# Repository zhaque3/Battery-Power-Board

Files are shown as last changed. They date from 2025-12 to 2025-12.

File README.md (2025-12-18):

# Battery Power Board

**Project:** Battery Power Board — power distribution, monitoring, and telemetry board for the University of Alberta EcoCar Prototype Vehicle.

**Vehicle:** 2025 Hydrogen Prototype (Sally). 1st Place, Shell Eco Marathon Hydrogen Prototype Category  
**Competition Year:** 2025

<p align="center">
  
</p>

---

## Overview

The Battery Power Board serves as the central power monitoring and distribution interface between the vehicle’s energy sources and downstream subsystems.  

It measures battery and regulated rail voltages and currents, monitors thermal conditions, computes energy usage, and communicates system status over the vehicle CAN bus.

---

## Key Functions

- Monitor battery input voltage and current
- Measure regulated output rails (12 V and 7 V)
- Monitor thermal conditions of critical power components
- Track energy consumption over time
- Display live system data on a local OLED
- Communicate telemetry and fault states over CAN bus
- Respond to vehicle safety events (e.g. hydrogen alarm)

---

## Power Architecture

### Input

- Battery input monitored via voltage divider
- Hall effect current sensing
- Designed for continuous monitoring under dynamic load conditions

### Output Rails

- **12 V Rail**
  - Voltage and current monitored
  - Supplies downstream electronics and subsystems
- **7 V Rail**
  - Voltage and current monitored
  - Intended for low power or auxiliary loads

---

## Sensing & Measurement

### Electrical Measurements

The board continuously measures:

- Battery input voltage
- Battery input current
- 12 V output voltage
- 12 V output current
- 7 V output voltage
- 7 V output current

These measurements allow real time estimation of power flow and system loading.

### Thermal Monitoring

- Multiple analog temperature sensors placed near:
  - Buck regulator
  - Output power stage
  - Control electronics
- Enables detection of abnormal thermal conditions during operation

---

## Energy Tracking

The board integrates measured voltage and current over time to estimate energy usage (joules).  
This data is used for:

- Efficiency analysis
- Post run performance evaluation
- Competition strategy optimization

---

## Local User Interface

- **SSD1306 OLED display**
- Displays:
  - Battery voltage and current
  - Output rail voltages and currents
  - Temperatures of key components
- Automatically switches to an alarm display when a fault condition is received

This allows quick diagnostics during testing without external tools.

---

## CAN Bus Integration

- Fully integrated into the vehicle CAN network
- Transmits:
  - Electrical measurements
  - Thermal data
  - System status flags
- Receives:
  - Safety and fault signals (e.g., hydrogen alarm)
  - Synchronization or status commands from other vehicle modules

The board reacts immediately to safety critical CAN messages by updating system state and user display.

---

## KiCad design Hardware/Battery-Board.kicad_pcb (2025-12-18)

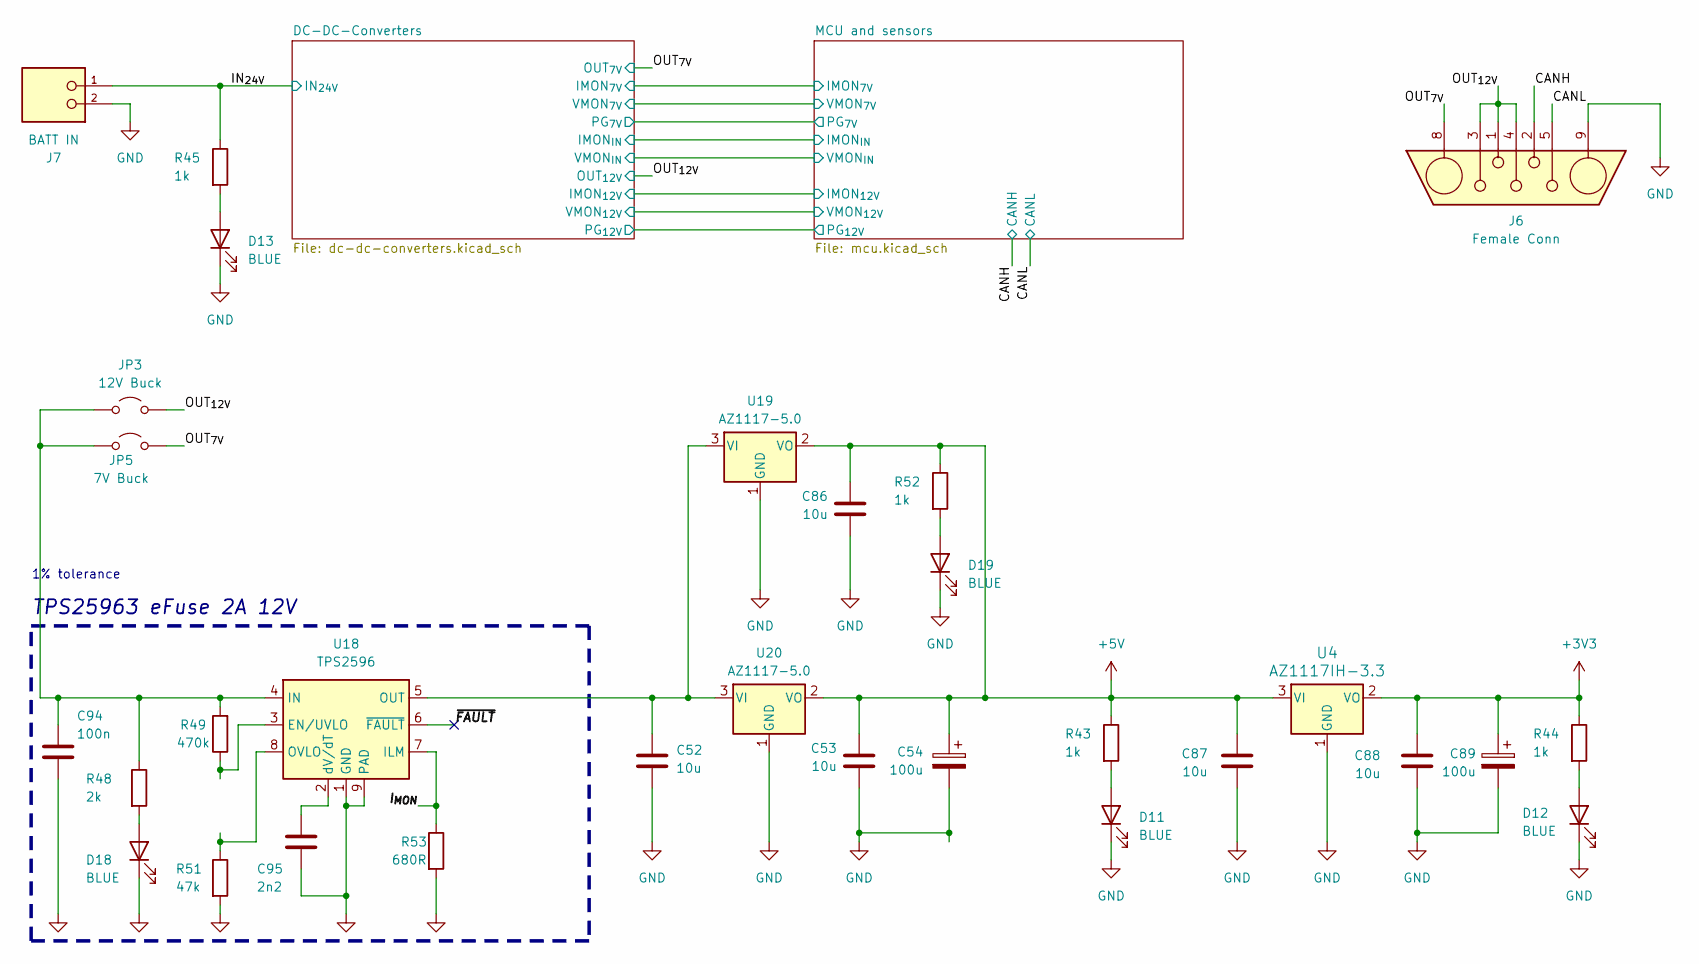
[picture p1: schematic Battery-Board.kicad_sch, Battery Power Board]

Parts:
C52, C53, C86, C87, C88: 10u; C_0805_2012Metric; LCSC# C15850
C54, C89: 100u; CP_Elec_6.3x9.9; LCSC# C72478
C94: 100n; C_0603_1608Metric; JLCPCB Part#(Optional) C28233
C95: 2n2; C_0603_1608Metric; JLCPCB Part#(Optional) C1531
D11, D12, D13, D18, D19: BLUE; LED_0603_1608Metric
J6: Female Conn; DB7W2-Female
J7: BATT IN; PHOENIX_1017521; PARTREV 04.01.2018
JP3: 12V Buck; J_0603_Triangular
JP5: 7V Buck; J_0603_Triangular
R43, R44, R45, R52: 1k; R_0603_1608Metric
R48: 2k; R_0603_1608Metric; JLCPCB Part#(Optional) C17604
R49: 470k; R_0603_1608Metric; JLCPCB Part#(optional) C17709
R51: 47k; R_0603_1608Metric; JLCPCB Part#(optional) C17713
R53: 680R; R_0603_1608Metric; JLCPCB Part#(Optional) C23220
U4: AZ1117IH-3.3; SOT-223-3_TabPin2
U18: TPS2596; TI_SO-PowerPAD-8
U19, U20: AZ1117-5.0; SOT-223-3_TabPin2

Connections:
+3V3: C88.1, C89.1, R44.1, U4.2 (VO); also elsewhere on the board
+5V: C53.1, C54.1, C86.1, C87.1, R43.1, R52.1, U4.3 (VI), U19.2 (VO), U20.2 (VO); also elsewhere on the board
/CANH: J6.2; also elsewhere on the board
/CANL: J6.5; also elsewhere on the board
/IN_{24V}: J7.1, R45.1; also elsewhere on the board
/I_{MON}: R53.1, U18.7 (ILM)
/OUT_{7V}: J6.8, JP5.2 (B); also elsewhere on the board
/OUT_{12V}: J6.1, J6.3, J6.4, JP3.2 (B); also elsewhere on the board
/~FAULT: U18.6 (~FAULT)
GND: C52.2, C53.2, C54.2, C86.2, C87.2, C88.2, C89.2, C94.2, C95.2, D11.1 (K), D12.1 (K), D13.1 (K), D18.1 (K), D19.1 (K), J6.9, J7.2, R51.2, R53.2, U4.1 (GND), U18.1 (GND), U18.9 (PAD), U19.1 (GND), U20.1 (GND); also elsewhere on the board
unnamed: D11.2 (A), R43.2
unnamed: D12.2 (A), R44.2
unnamed: D13.2 (A), R45.2
unnamed: D18.2 (A), R48.2
unnamed: D19.2 (A), R52.2
unnamed: C94.1, JP3.1 (A), JP5.1 (A), R48.1, R49.2, U18.4 (IN)
unnamed 90: R49.1, U18.3 (EN/UVLO); also elsewhere on the board
unnamed: C52.1, U18.5 (OUT), U19.3 (VI), U20.3 (VI)
unnamed 92: R51.1, U18.8 (OVLO); also elsewhere on the board
unnamed: C95.1, U18.2 (dV/dT)

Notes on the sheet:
TPS25963 eFuse 2A 12V
1% tolerance

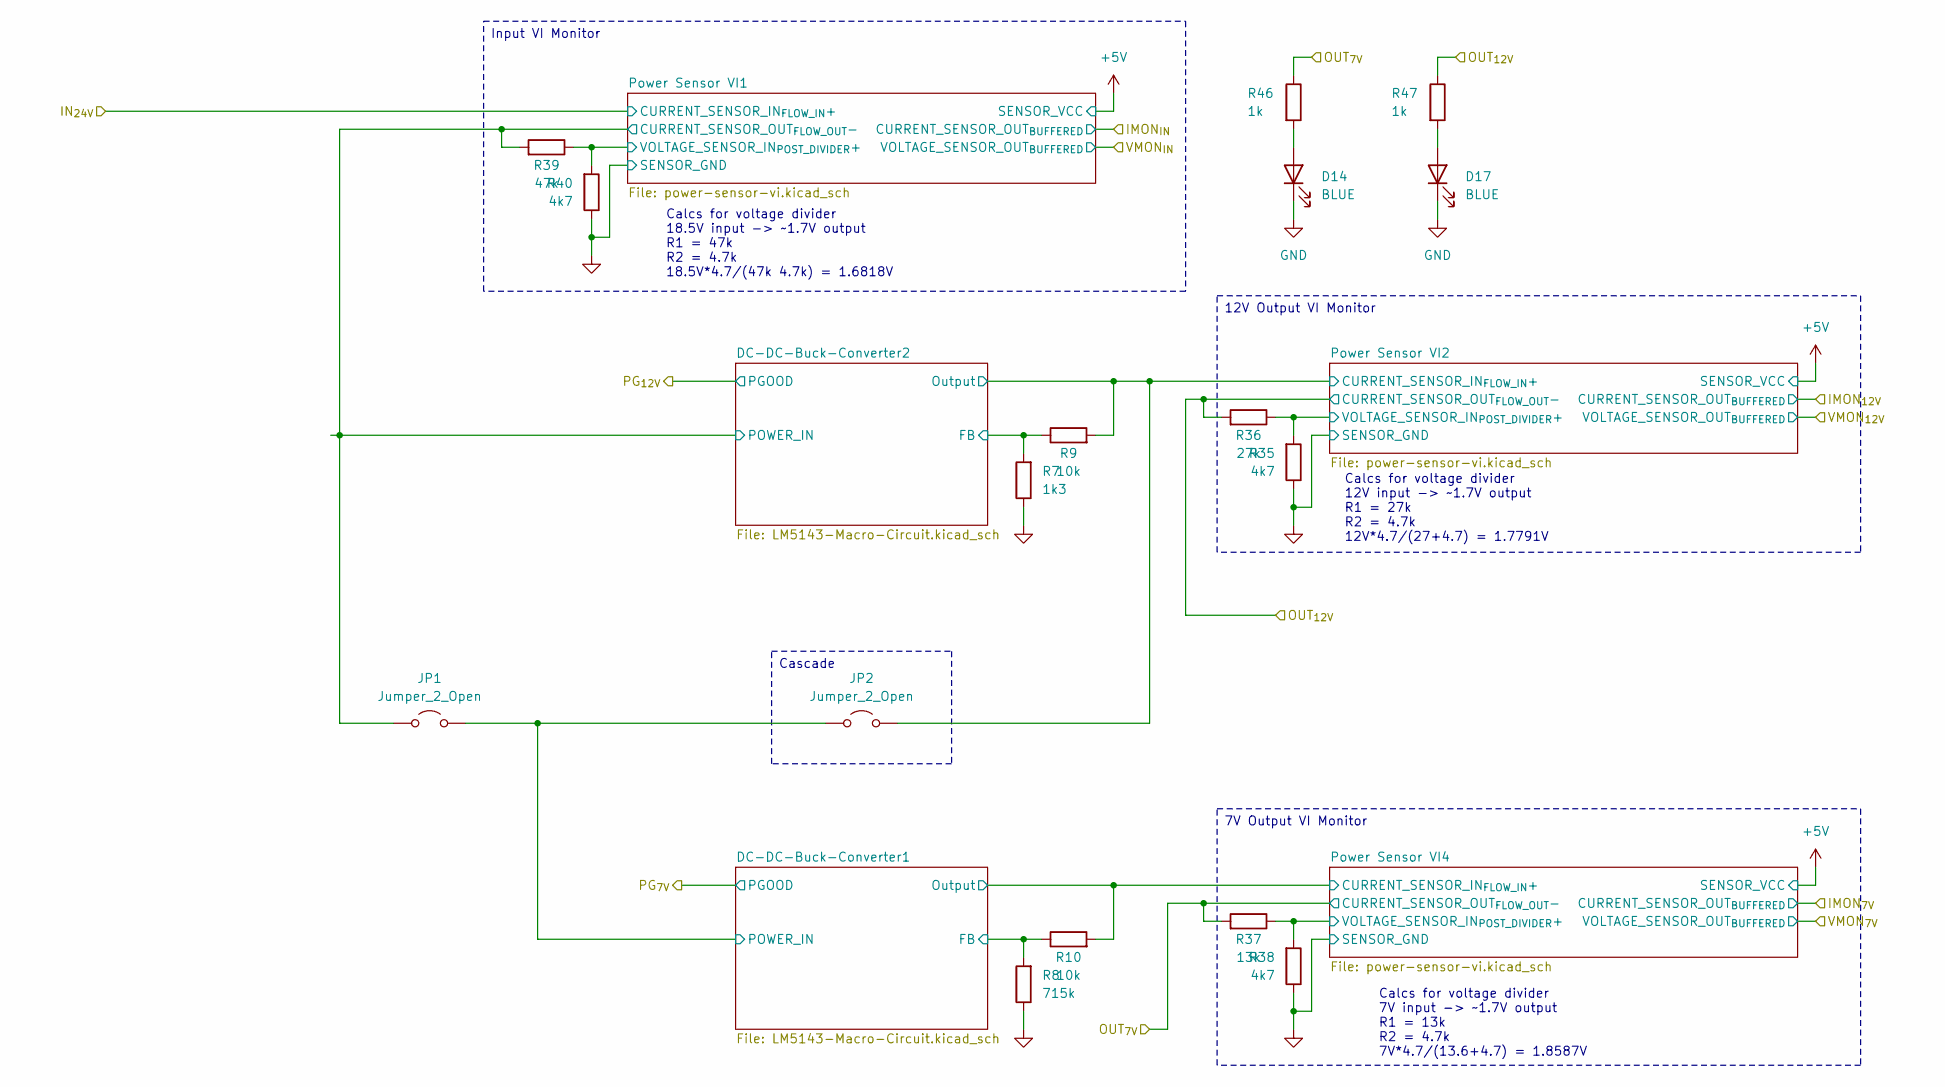
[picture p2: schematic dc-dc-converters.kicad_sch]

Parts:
D14, D17: BLUE; LED_0603_1608Metric
JP1, JP2: Jumper_2_Open; Jumper_Micro-Miniature_P5.375mm
R7: 1k3; R_0603_1608Metric
R8: 715k; R_0603_1608Metric
R9, R10: 10k; R_0603_1608Metric
R35, R38, R40: 4k7; R_0603_1608Metric
R36: 27k; R_0603_1608Metric
R37: 13k; R_0603_1608Metric
R39: 47k; R_0603_1608Metric
R46, R47: 1k; R_0603_1608Metric

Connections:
/DC-DC-Converters/DC-DC-Buck-Converter1/FB: R8.2, R10.1; also elsewhere on the board
/DC-DC-Converters/DC-DC-Buck-Converter1/Output: R10.2; also elsewhere on the board
/DC-DC-Converters/DC-DC-Buck-Converter1/POWER_IN: JP1.2 (B), JP2.1 (A); also elsewhere on the board
/DC-DC-Converters/DC-DC-Buck-Converter2/FB: R7.2, R9.1; also elsewhere on the board
/DC-DC-Converters/DC-DC-Buck-Converter2/Output: JP2.2 (B), R9.2; also elsewhere on the board
/DC-DC-Converters/DC-DC-Buck-Converter2/POWER_IN: JP1.1 (A), R39.2; also elsewhere on the board
/DC-DC-Converters/Power Sensor VI1/VOLTAGE_SENSOR_IN_{POST_DIVIDER}+: R39.1, R40.2; also elsewhere on the board
/DC-DC-Converters/Power Sensor VI2/VOLTAGE_SENSOR_IN_{POST_DIVIDER}+: R35.2, R36.1; also elsewhere on the board
/DC-DC-Converters/Power Sensor VI4/VOLTAGE_SENSOR_IN_{POST_DIVIDER}+: R37.1, R38.2; also elsewhere on the board
/OUT_{7V}: R37.2, R46.1; also elsewhere on the board
/OUT_{12V}: R36.2, R47.1; also elsewhere on the board
GND: D14.1 (K), D17.1 (K), R7.1, R8.1, R35.1, R38.1, R40.1; also elsewhere on the board
unnamed: D14.2 (A), R46.2
unnamed: D17.2 (A), R47.2

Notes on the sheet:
Calcs for voltage divider 18.5V input -> ~1.7V output R1 = 47k R2 = 4.7k 18.5V*4.7/(47k 4.7k) = 1.6818V
Calcs for voltage divider 7V input -> ~1.7V output R1 = 13k R2 = 4.7k 7V*4.7/(13.6+4.7) = 1.8587V
Calcs for voltage divider 12V input -> ~1.7V output R1 = 27k R2 = 4.7k 12V*4.7/(27+4.7) = 1.7791V
12V Output VI Monitor
7V Output VI Monitor
Input VI Monitor
Cascade

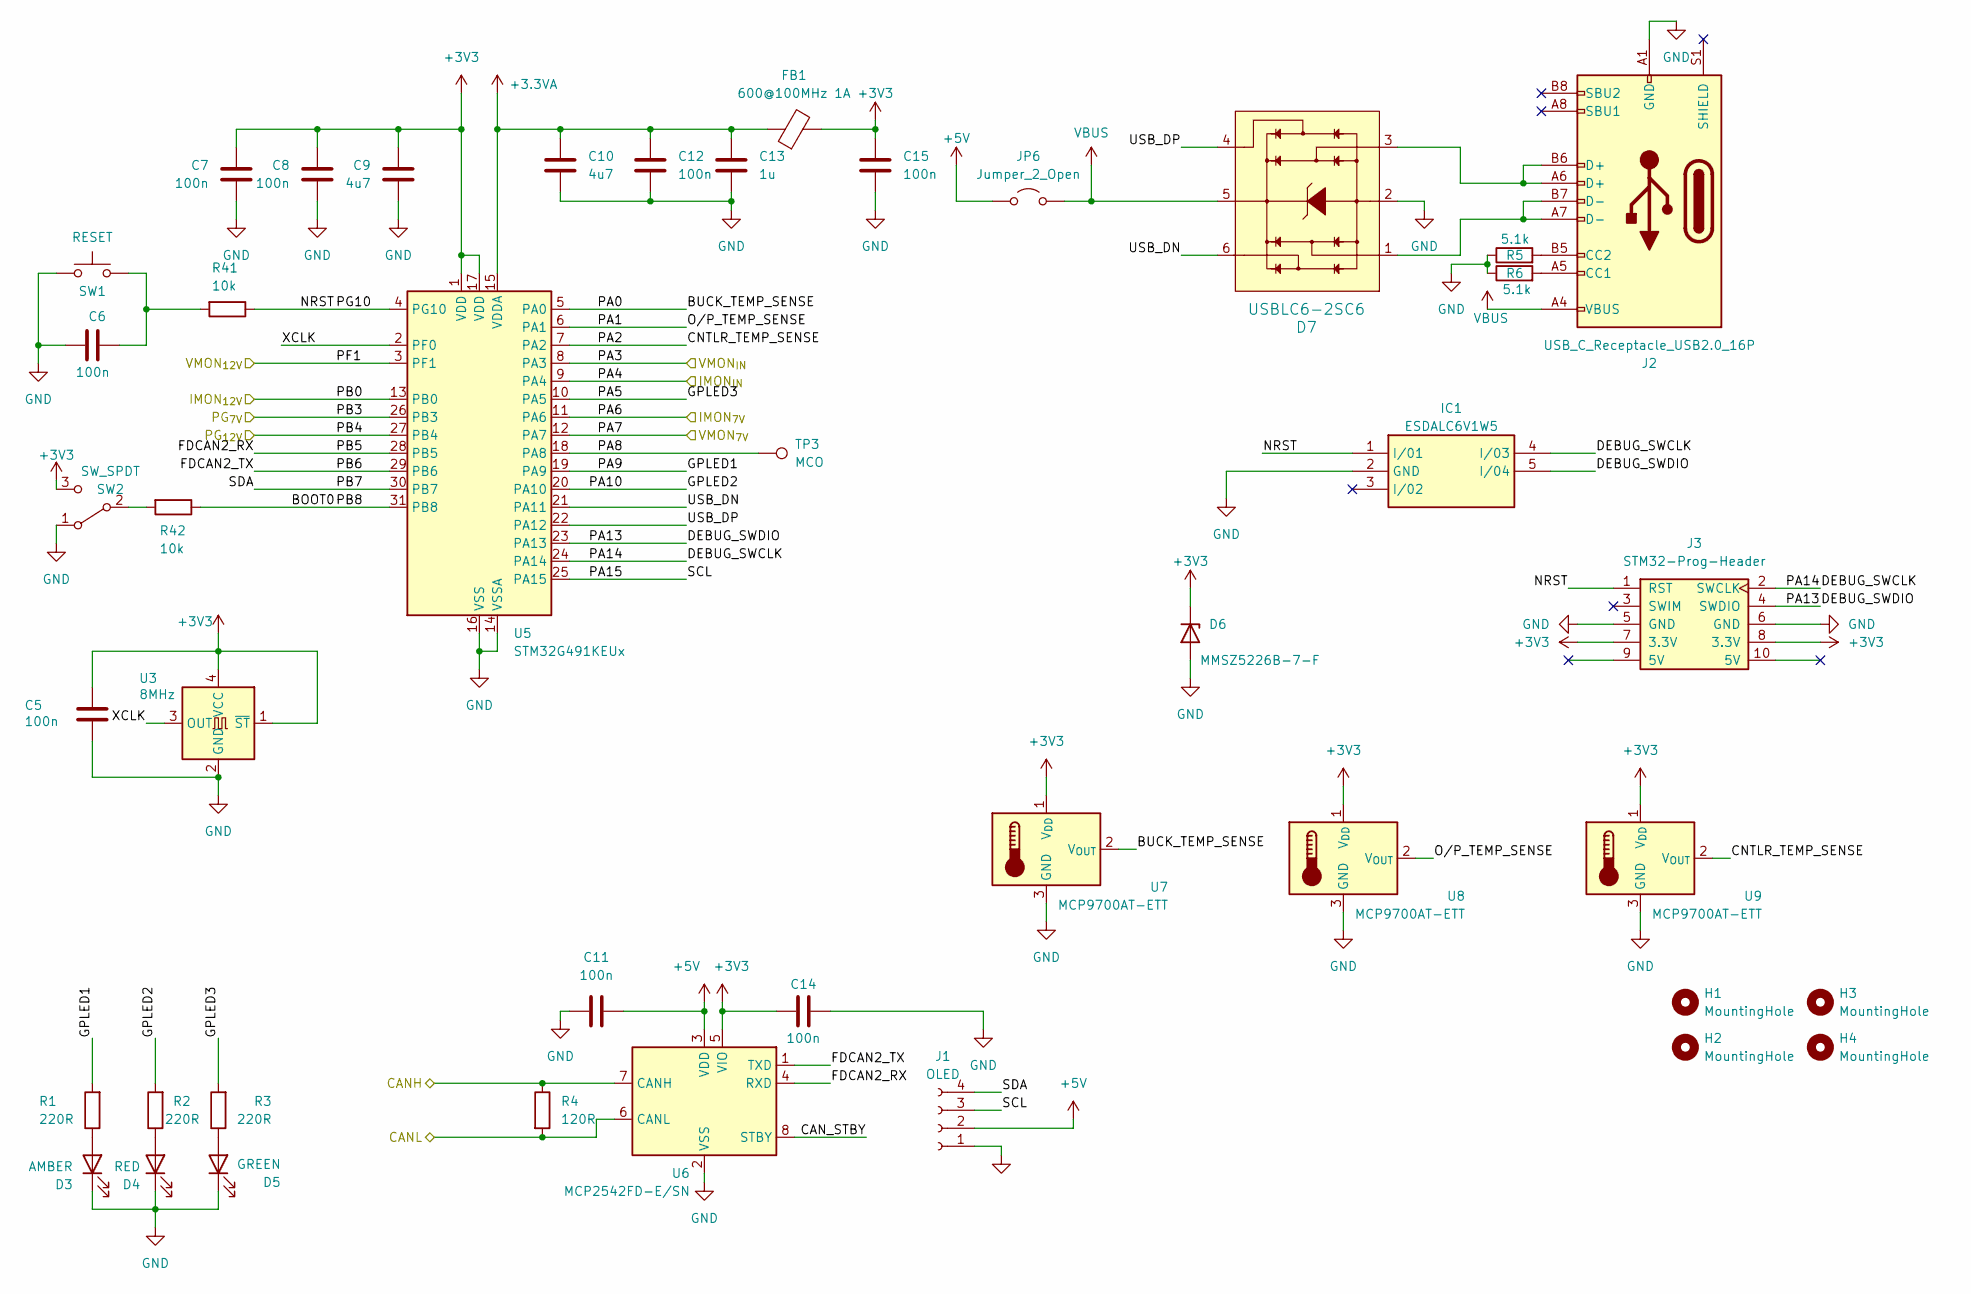
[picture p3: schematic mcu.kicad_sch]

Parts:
C5, C6, C11, C14: 100n; C_0603_1608Metric; JLCPCB Part#(Optional) C1525
C7, C8: 100n; C_0603_1608Metric
C9: 4u7; C_0805_2012Metric
C10: 4u7; C_0603_1608Metric; JLCPCB Part#(Optional) C96446
C12: 100n; C_0603_1608Metric; JLCPCB Part#(Optional) C96446
C13: 1u; C_0603_1608Metric; JLCPCB Part#(Optional) C28323
C15: 100n; C_0603_1608Metric; JLCPCB Part#(Optional) C28323
D3: AMBER; LED_0603_1608Metric; JLCPCB Part#(Optional) C2296
D4: RED; LED_0603_1608Metric; JLCPCB Part#(Optional) C84256
D5: GREEN; LED_0603_1608Metric; JLCPCB Part#(Optional) C2297
D6: MMSZ5226B-7-F; D_SOD-123; Digikey # MMSZ5226B-FDICT-ND
D7: USBLC6-2SC6; TSOT-23-6; Digikey # 497-5235-1-ND
FB1: 600@100MHz 1A; L_0603_1608Metric; Digikey # 1934-1474-1-ND
H1, H2, H3, H4: MountingHole; MountingHole_3.5mm
IC1: ESDALC6V1W5; SOT65P210X110-5N; JLCPCB Part#(Optional) C2827626
J1: OLED; Display_128x64_096_I2C
J2: USB_C_Receptacle_USB2.0_16P; USB_C_Receptacle_GCT_USB4105-xx-A_16P_TopMnt_Horizontal
J3: STM32-Prog-Header; PinHeader_2x05_P2.54mm_Vertical
JP6: Jumper_2_Open
R1, R2, R3: 220R; R_0603_1608Metric; JLCPCB Part#(Optional) C17557
R4: 120R; R_0603_1608Metric
R5, R6: 5.1k; R_0603_1608Metric; JLCPCB Part#(Optional) C17557
R41, R42: 10k; R_0603_1608Metric; JLCPCB Part#(Optional) C17557
SW1: RESET; SW_PUSH_6mm_H5mm
SW2: SW_SPDT; SW_SPDT_PCM12; Digikey # 2223-SLW-66527511-SMT-TRCT-ND
TP3: MCO; PinHeader_1x01_P2.54mm_Vertical
U3: 8MHz; Crystal_SMD_3225-4Pin_3.2x2.5mm; Digikey # 535-ASE-8.000MHZ-L-C-TCT-ND
U5: STM32G491KEUx; QFN-32-1EP_5x5mm_P0.5mm_EP3.45x3.45mm
U6: MCP2542FD-E/SN; SOIC-8_3.9x4.9mm_P1.27mm; Digikey # MCP2542FD-E/SN-ND
U7, U8, U9: MCP9700AT-ETT; SOT-23; LCSC# C42288

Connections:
+3.3VA: C10.1, C12.1, C13.1, FB1.1, U5.15 (VDDA)
+3V3: C5.2, C7.1, C8.1, C9.1, C14.2, C15.1, D6.1 (K), FB1.2, J3.7 (3.3V), J3.8 (3.3V), SW2.3 (C), U3.1 (~ST), U3.4 (VCC), U5.1 (VDD), U5.17 (VDD), U6.5 (VIO), U7.1 (V_{DD}), U8.1 (V_{DD}), U9.1 (V_{DD}); also elsewhere on the board
+5V: C11.2, J1.2, JP6.1 (A), U6.3 (VDD); also elsewhere on the board
/CANH: R4.1, U6.7 (CANH); also elsewhere on the board
/CANL: R4.2, U6.6 (CANL); also elsewhere on the board
/MCU and sensors/BUCK_TEMP_SENSE: U5.5 (PA0), U7.2 (V_{OUT})
/MCU and sensors/CAN_STBY: U6.8 (STBY)
/MCU and sensors/CNTLR_TEMP_SENSE: U5.7 (PA2), U9.2 (V_{OUT})
/MCU and sensors/DEBUG_SWCLK: IC1.4 (I/03), J3.2 (SWCLK), U5.24 (PA14)
/MCU and sensors/DEBUG_SWDIO: IC1.5 (I/04), J3.4 (SWDIO), U5.23 (PA13)
/MCU and sensors/FDCAN2_RX: U5.28 (PB5), U6.4 (RXD)
/MCU and sensors/FDCAN2_TX: U5.29 (PB6), U6.1 (TXD)
/MCU and sensors/GPLED1: R1.2, U5.19 (PA9)
/MCU and sensors/GPLED2: R2.2, U5.20 (PA10)
/MCU and sensors/GPLED3: R3.2, U5.10 (PA5)
/MCU and sensors/NRST: IC1.1 (I/01), J3.1 (RST), R41.1, U5.4 (PG10)
/MCU and sensors/O/P_TEMP_SENSE: U5.6 (PA1), U8.2 (V_{OUT})
/MCU and sensors/PA3: U5.8 (PA3); also elsewhere on the board
/MCU and sensors/PA4: U5.9 (PA4); also elsewhere on the board
/MCU and sensors/PA6: U5.11 (PA6); also elsewhere on the board
/MCU and sensors/PA7: U5.12 (PA7); also elsewhere on the board
/MCU and sensors/PA8: TP3.1, U5.18 (PA8)
/MCU and sensors/PA15: J1.3, U5.25 (PA15)
/MCU and sensors/PB0: U5.13 (PB0); also elsewhere on the board
/MCU and sensors/PB3: U5.26 (PB3); also elsewhere on the board
/MCU and sensors/PB4: U5.27 (PB4); also elsewhere on the board
/MCU and sensors/PB7: J1.4, U5.30 (PB7)
/MCU and sensors/PF1: U5.3 (PF1); also elsewhere on the board
/MCU and sensors/USB_DN: D7.6, U5.21 (PA11)
/MCU and sensors/USB_DP: D7.4, U5.22 (PA12)
/MCU and sensors/XCLK: U3.3 (OUT), U5.2 (PF0)
GND: C5.1, C6.1, C7.2, C8.2, C9.2, C10.2, C11.1, C12.2, C13.2, C14.1, C15.2, D3.1 (K), D4.1 (K), D5.1 (K), D6.2 (A), D7.2, IC1.2 (GND), J1.1, J2.A1 (GND), J2.A12 (GND), J2.B1 (GND), J2.B12 (GND), J3.5 (GND), J3.6 (GND), R5.1, R6.1, SW1.1, SW2.1 (A), U3.2 (GND), U5.14 (VSSA), U5.16 (VSS), U5.32 (VSS), U5.33 (VSS), U6.2 (VSS), U6.9 (VSS), U7.3 (GND), U8.3 (GND), U9.3 (GND); also elsewhere on the board
unnamed: C6.2, R41.2, SW1.2
unnamed: D3.2 (A), R1.1
unnamed: D4.2 (A), R2.1
unnamed: D5.2 (A), R3.1
unnamed: D7.1, J2.A7 (D-), J2.B7 (D-)
unnamed: D7.3, J2.A6 (D+), J2.B6 (D+)
unnamed: J2.A5 (CC1), R6.2
unnamed: J2.B5 (CC2), R5.2
unnamed: R42.2, SW2.2 (B)
unnamed: R42.1, U5.31 (PB8)
VBUS: D7.5, J2.A4 (VBUS), J2.A9 (VBUS), J2.B4 (VBUS), J2.B9 (VBUS), JP6.2 (B)

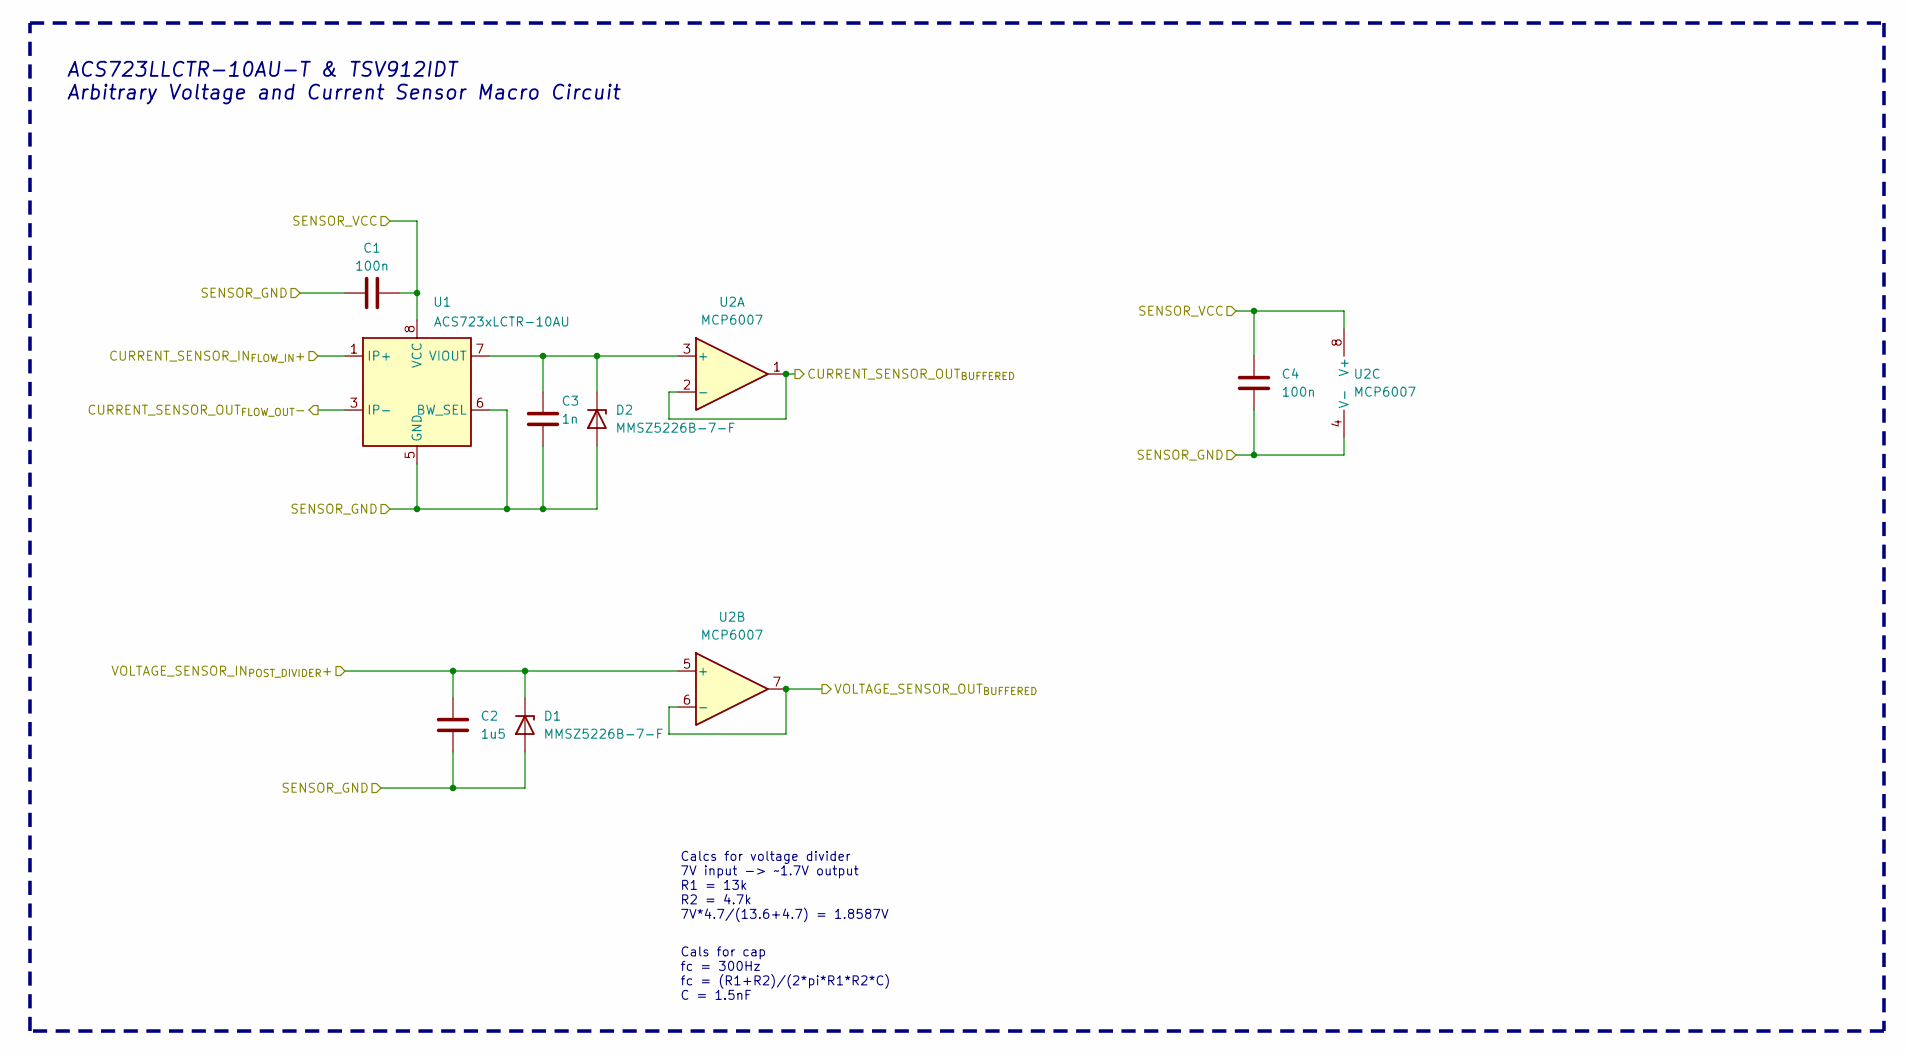
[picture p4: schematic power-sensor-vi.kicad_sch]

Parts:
C1, C4: 100n; C_0603_1608Metric; Digikey # CC0603KRX7R7BB104
C2: 1u5; C_0603_1608Metric; JLCPCB Part#(Optional) C28323
C3: 1n; C_0603_1608Metric; JLCPCB Part#(Optional) C1523
D1, D2: MMSZ5226B-7-F; D_SOD-123; Digikey # MMSZ5226B-FDICT-ND
U1: ACS723xLCTR-10AU; SOIC-8_3.9x4.9mm_P1.27mm
U2: MCP6007; SOIC-8_3.9x4.9mm_P1.27mm

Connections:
+5V: C1.1, C4.1, U1.8 (VCC), U2.8 (V+); also elsewhere on the board
/DC-DC-Converters/DC-DC-Buck-Converter2/POWER_IN: U1.3 (IP-), U1.4 (IP-); also elsewhere on the board
/DC-DC-Converters/Power Sensor VI1/VOLTAGE_SENSOR_IN_{POST_DIVIDER}+: C2.1, D1.1 (K), U2.5 (+); also elsewhere on the board
/IN_{24V}: U1.1 (IP+), U1.2 (IP+); also elsewhere on the board
/MCU and sensors/PA3: U2.6 (-), U2.7; also elsewhere on the board
/MCU and sensors/PA4: U2.1, U2.2 (-); also elsewhere on the board
GND: C1.2, C2.2, C3.2, C4.2, D1.2 (A), D2.2 (A), U1.5 (GND), U1.6 (BW_SEL), U2.4 (V-); also elsewhere on the board
unnamed: C3.1, D2.1 (K), U1.7 (VIOUT), U2.3 (+)

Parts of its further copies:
C16, C19, C90, C93: 100n; C_0603_1608Metric; Digikey # CC0603KRX7R7BB104
C17, C91: 1u5; C_0603_1608Metric; JLCPCB Part#(Optional) C28323
C18, C92: 1n; C_0603_1608Metric; JLCPCB Part#(Optional) C1523
D9, D10, D15, D16: MMSZ5226B-7-F; D_SOD-123; Digikey # MMSZ5226B-FDICT-ND
U10, U28: ACS723xLCTR-10AU; SOIC-8_3.9x4.9mm_P1.27mm
U11, U29: MCP6007; SOIC-8_3.9x4.9mm_P1.27mm

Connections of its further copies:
+5V: C16.1, C19.1, C90.1, C93.1, U10.8 (VCC), U11.8 (V+), U28.8 (VCC), U29.8 (V+); also elsewhere on the board
/DC-DC-Converters/DC-DC-Buck-Converter1/Output: U28.1 (IP+), U28.2 (IP+); also elsewhere on the board
/DC-DC-Converters/DC-DC-Buck-Converter2/Output: U10.1 (IP+), U10.2 (IP+); also elsewhere on the board
/DC-DC-Converters/Power Sensor VI2/VOLTAGE_SENSOR_IN_{POST_DIVIDER}+: C17.1, D9.1 (K), U11.5 (+); also elsewhere on the board
/DC-DC-Converters/Power Sensor VI4/VOLTAGE_SENSOR_IN_{POST_DIVIDER}+: C91.1, D15.1 (K), U29.5 (+); also elsewhere on the board
/MCU and sensors/PA6: U29.1, U29.2 (-); also elsewhere on the board
/MCU and sensors/PA7: U29.6 (-), U29.7; also elsewhere on the board
/MCU and sensors/PB0: U11.1, U11.2 (-); also elsewhere on the board
/MCU and sensors/PF1: U11.6 (-), U11.7; also elsewhere on the board
/OUT_{7V}: U28.3 (IP-), U28.4 (IP-); also elsewhere on the board
/OUT_{12V}: U10.3 (IP-), U10.4 (IP-); also elsewhere on the board
GND: C16.2, C17.2, C18.2, C19.2, C90.2, C91.2, C92.2, C93.2, D9.2 (A), D10.2 (A), D15.2 (A), D16.2 (A), U10.5 (GND), U10.6 (BW_SEL), U11.4 (V-), U28.5 (GND), U28.6 (BW_SEL), U29.4 (V-); also elsewhere on the board
unnamed: C18.1, D10.1 (K), U10.7 (VIOUT), U11.3 (+)
unnamed: C92.1, D16.1 (K), U28.7 (VIOUT), U29.3 (+)

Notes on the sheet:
ACS723LLCTR-10AU-T & TSV912IDT Arbitrary Voltage and Current Sensor Macro Circuit
Cals for cap fc = 300Hz fc = (R1+R2)/(2*pi*R1*R2*C) C = 1.5nF
Calcs for voltage divider 7V input -> ~1.7V output R1 = 13k R2 = 4.7k 7V*4.7/(13.6+4.7) = 1.8587V

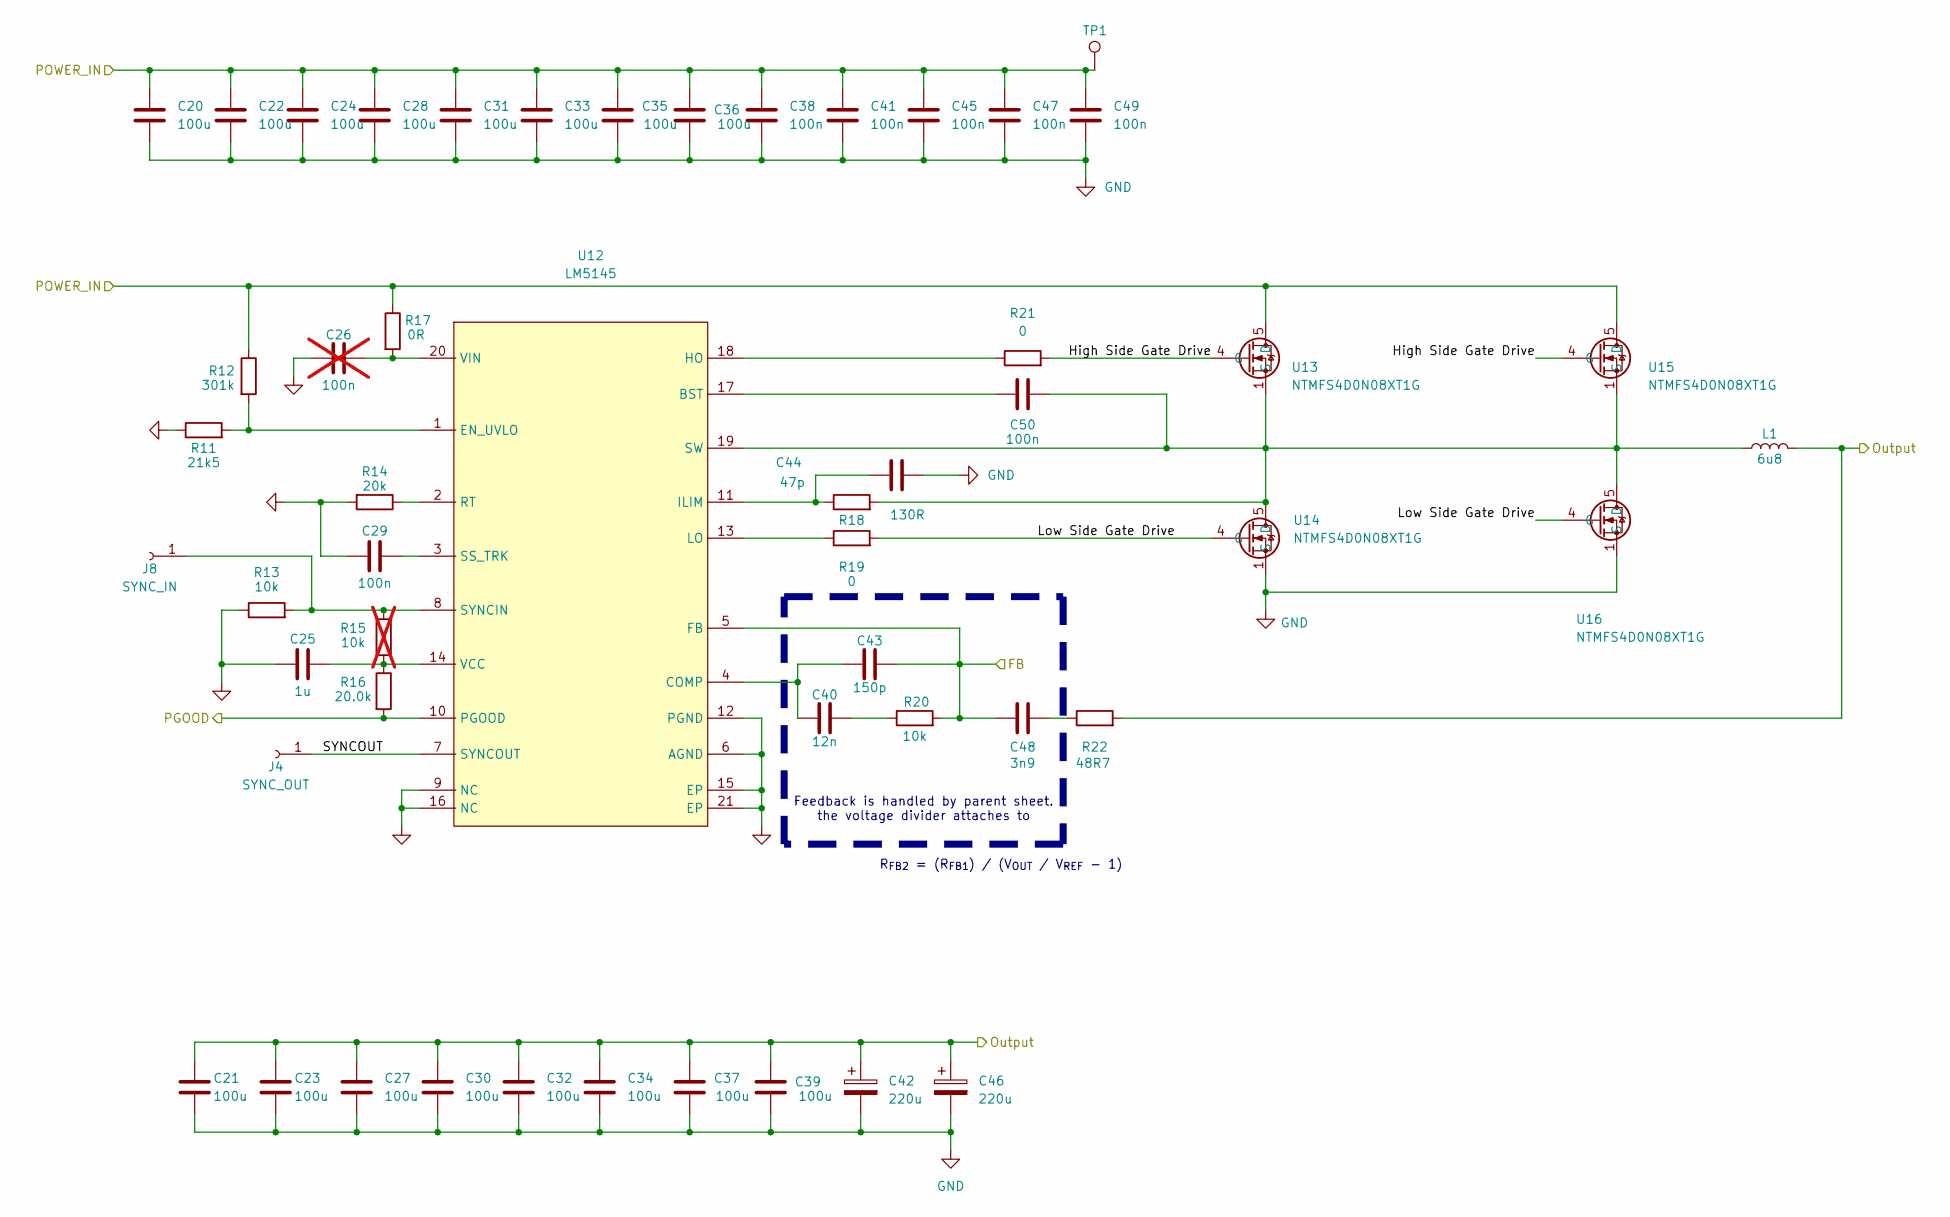
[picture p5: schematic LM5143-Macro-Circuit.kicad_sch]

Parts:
C20, C21, C22, C23, C24, C27, C28, C30, C31, C32, C33, C34, C35, C36, C37, C39: 100u; C_1210_3225Metric
C25: 1u; C_0603_1608Metric
C26: 100n; C_0603_1608Metric; not fitted
C29, C38, C41, C45, C47, C49, C50: 100n; C_0603_1608Metric
C40: 12n; C_0603_1608Metric
C42, C46: 220u; CAP_EEE1HA221P
C43: 150p; C_0603_1608Metric
C44: 47p; C_0603_1608Metric
C48: 3n9; C_0603_1608Metric
J4: SYNC_OUT; PinHeader_1x01_P2.54mm_Vertical
J8: SYNC_IN; PinHeader_1x01_P2.54mm_Vertical
L1: 6u8; L_Bourns_SRR1208_12.7x12.7mm
R11: 21k5; R_0603_1608Metric
R12: 301k; R_0603_1608Metric
R13, R20: 10k; R_0603_1608Metric
R14: 20k; R_0603_1608Metric
R15: 10k; R_0603_1608Metric; not fitted
R16: 20.0k; R_0603_1608Metric
R17: 0R; R_0603_1608Metric
R18: 130R; R_0603_1608Metric
R19, R21: 0; R_0603_1608Metric
R22: 48R7; R_0603_1608Metric
TP1: TestPoint; PinHeader_1x01_P2.54mm_Vertical
U12: LM5145; Texas_RGY_R-PVQFN-N20_EP2.05x3.05mm_ThermalVias
U13, U14, U15, U16: NTMFS4D0N08XT1G; PowerMosDFNHybrid

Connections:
/DC-DC-Converters/DC-DC-Buck-Converter1/FB: C43.2, C48.1, R20.2, U12.5 (FB); also elsewhere on the board
/DC-DC-Converters/DC-DC-Buck-Converter1/High Side Gate Drive: R21.2, U13.4 (G), U15.4 (G)
/DC-DC-Converters/DC-DC-Buck-Converter1/Low Side Gate Drive: R19.2, U14.4 (G), U16.4 (G)
/DC-DC-Converters/DC-DC-Buck-Converter1/Output: C21.1, C23.1, C27.1, C30.1, C32.1, C34.1, C37.1, C39.1, C42.1, C46.1, L1.2, R22.2; also elsewhere on the board
/DC-DC-Converters/DC-DC-Buck-Converter1/POWER_IN: C20.1, C22.1, C24.1, C28.1, C31.1, C33.1, C35.1, C36.1, C38.1, C41.1, C45.1, C47.1, C49.1, R12.1, R17.1, TP1.1, U13.5 (D), U15.5 (D); also elsewhere on the board
/DC-DC-Converters/DC-DC-Buck-Converter1/SYNCOUT: J4.1, U12.7 (SYNCOUT)
/MCU and sensors/PB3: R16.2, U12.10 (PGOOD); also elsewhere on the board
GND: C20.2, C21.2, C22.2, C23.2, C24.2, C25.1, C26.1, C27.2, C28.2, C29.1, C30.2, C31.2, C32.2, C33.2, C34.2, C35.2, C36.2, C37.2, C38.2, C39.2, C41.2, C42.2, C44.1, C45.2, C46.2, C47.2, C49.2, R11.1, R13.1, R14.2, U12.6 (AGND), U12.9 (NC), U12.12 (PGND), U12.15 (EP), U12.16 (NC), U12.21 (EP), U14.1 (S), U14.2 (S), U14.3 (S), U16.1 (S), U16.2 (S), U16.3 (S); also elsewhere on the board
unnamed: C40.2, R20.1
unnamed: C48.2, R22.1
unnamed: J8.1, R13.2, R15.1, U12.8 (SYNCIN)
unnamed: C50.2, U12.17 (BST)
unnamed: C40.1, C43.1, U12.4 (COMP)
unnamed: R11.2, R12.2, U12.1 (EN_UVLO)
unnamed: R21.1, U12.18 (HO)
unnamed: C44.2, R18.1, U12.11 (ILIM)
unnamed: R19.1, U12.13 (LO)
unnamed: R14.1, U12.2 (RT)
unnamed: C29.2, U12.3 (SS_TRK)
unnamed: C50.1, L1.1, R18.2, U12.19 (SW), U13.1 (S), U13.2 (S), U13.3 (S), U14.5 (D), U15.1 (S), U15.2 (S), U15.3 (S), U16.5 (D)
unnamed: C25.2, R15.2, R16.1, U12.14 (VCC)
unnamed: C26.2, R17.2, U12.20 (VIN)

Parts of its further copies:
C55, C56, C57, C58, C59, C62, C63, C65, C66, C67, C68, C69, C70, C71, C72, C74: 100u; C_1210_3225Metric
C60: 1u; C_0603_1608Metric
C61: 100n; C_0603_1608Metric; not fitted
C73, C76, C80, C82, C84, C85: 100n; C_0603_1608Metric
C77, C81: 220u; CAP_EEE1HA221P
J5: SYNC_OUT; PinHeader_1x01_P2.54mm_Vertical
J9: SYNC_IN; PinHeader_1x01_P2.54mm_Vertical
L2: 6u8; L_Bourns_SRR1208_12.7x12.7mm
R25, R32: 10k; R_0603_1608Metric
R27: 10k; R_0603_1608Metric; not fitted
R28: 20.0k; R_0603_1608Metric
R31, R33: 0; R_0603_1608Metric
TP2: TestPoint; PinHeader_1x01_P2.54mm_Vertical
U21: LM5145; Texas_RGY_R-PVQFN-N20_EP2.05x3.05mm_ThermalVias
U22, U23, U24, U25: NTMFS4D0N08XT1G; PowerMosDFNHybrid

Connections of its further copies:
/DC-DC-Converters/DC-DC-Buck-Converter2/FB: R32.2, U21.5 (FB); also elsewhere on the board
/DC-DC-Converters/DC-DC-Buck-Converter2/High Side Gate Drive: R33.2, U22.4 (G), U24.4 (G)
/DC-DC-Converters/DC-DC-Buck-Converter2/Low Side Gate Drive: R31.2, U23.4 (G), U25.4 (G)
/DC-DC-Converters/DC-DC-Buck-Converter2/Output: C56.1, C58.1, C62.1, C65.1, C67.1, C69.1, C72.1, C74.1, C77.1, C81.1, L2.2; also elsewhere on the board
/DC-DC-Converters/DC-DC-Buck-Converter2/POWER_IN: C55.1, C57.1, C59.1, C63.1, C66.1, C68.1, C70.1, C71.1, C73.1, C76.1, C80.1, C82.1, C84.1, TP2.1, U22.5 (D), U24.5 (D); also elsewhere on the board
/DC-DC-Converters/DC-DC-Buck-Converter2/SYNCOUT: J5.1, U21.7 (SYNCOUT)
/MCU and sensors/PB4: R28.2, U21.10 (PGOOD); also elsewhere on the board
GND: C55.2, C56.2, C57.2, C58.2, C59.2, C60.1, C61.1, C62.2, C63.2, C65.2, C66.2, C67.2, C68.2, C69.2, C70.2, C71.2, C72.2, C73.2, C74.2, C76.2, C77.2, C80.2, C81.2, C82.2, C84.2, R25.1, U21.6 (AGND), U21.9 (NC), U21.12 (PGND), U21.15 (EP), U21.16 (NC), U21.21 (EP), U23.1 (S), U23.2 (S), U23.3 (S), U25.1 (S), U25.2 (S), U25.3 (S); also elsewhere on the board
unnamed 55: R32.1; also elsewhere on the board
unnamed: J9.1, R25.2, R27.1, U21.8 (SYNCIN)
unnamed: C85.2, U21.17 (BST)
unnamed 95: U21.4 (COMP); also elsewhere on the board
unnamed 96: U21.1 (EN_UVLO); also elsewhere on the board
unnamed: R33.1, U21.18 (HO)
unnamed 98: U21.11 (ILIM); also elsewhere on the board
unnamed: R31.1, U21.13 (LO)
unnamed 100: U21.2 (RT); also elsewhere on the board
unnamed 101: U21.3 (SS_TRK); also elsewhere on the board
unnamed 102: C85.1, L2.1, U21.19 (SW), U22.1 (S), U22.2 (S), U22.3 (S), U23.5 (D), U24.1 (S), U24.2 (S), U24.3 (S), U25.5 (D); also elsewhere on the board
unnamed: C60.2, R27.2, R28.1, U21.14 (VCC)
unnamed 104: C61.2, U21.20 (VIN); also elsewhere on the board

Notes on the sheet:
Feedback is handled by parent sheet. the voltage divider attaches to
R_{FB2} = (R_{FB1}) / (V_{OUT} / V_{REF} - 1)

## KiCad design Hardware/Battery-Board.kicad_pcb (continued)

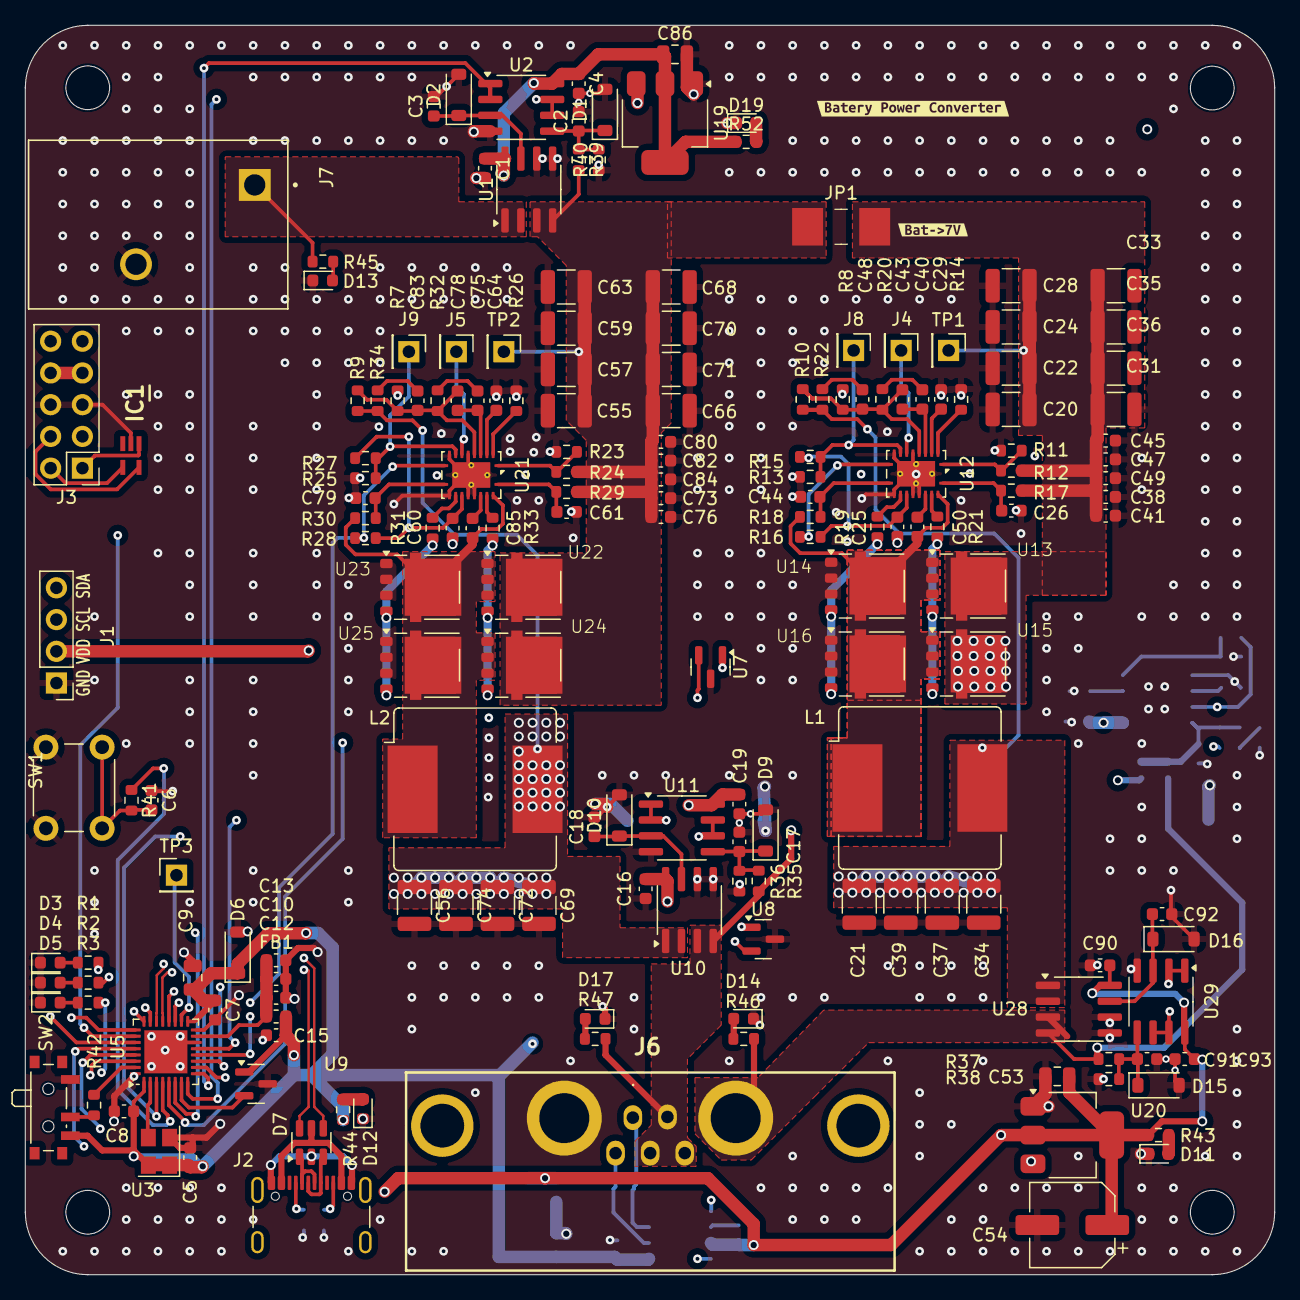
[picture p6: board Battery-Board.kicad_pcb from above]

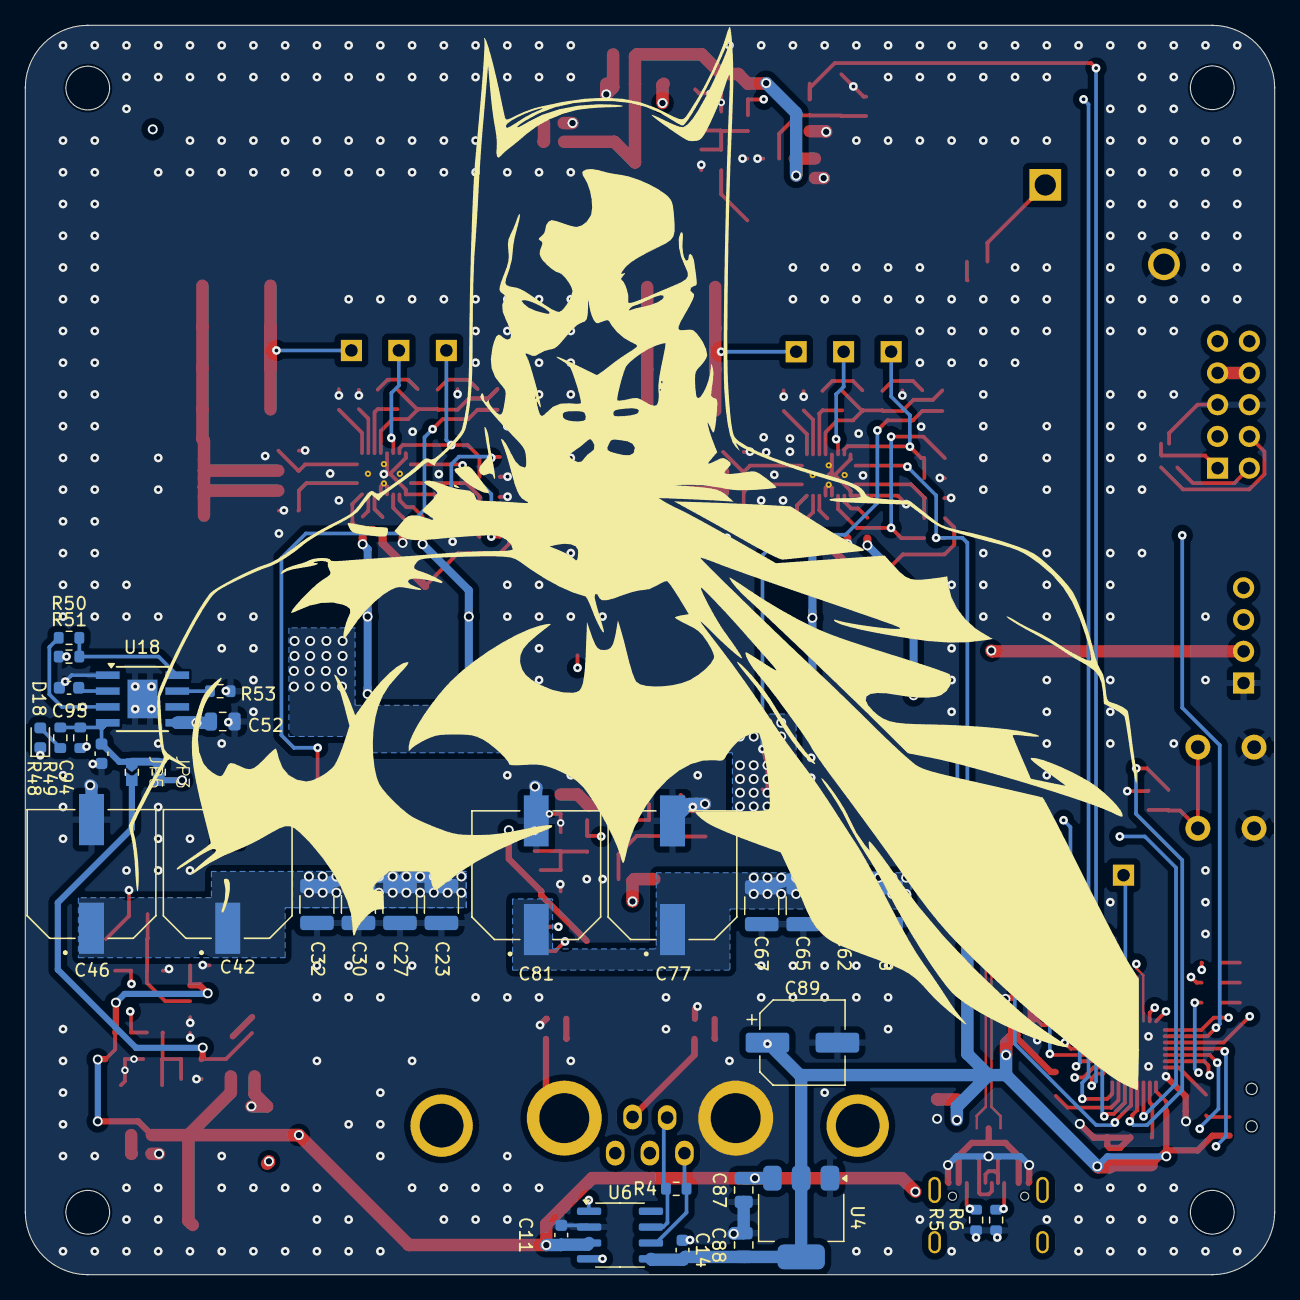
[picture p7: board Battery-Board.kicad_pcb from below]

Board: 4 copper layers, 100.0 x 100.0 mm, 220 parts (36 on the bottom side), 104 nets.

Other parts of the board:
C64: 47n; C_0603_1608Metric
C75: 5600pF; C_0603_1608Metric
C78: 150pF; C_0603_1608Metric
C79: 15pF; C_0603_1608Metric
C83: 1800pF; C_0603_1608Metric
R23: 18.2k; R_0603_1608Metric
R24: 250k; R_0603_1608Metric
R26: 46.4k; R_0603_1608Metric
R29: 2.2; R_0603_1608Metric
R30: 680R; R_0603_1608Metric
R34: 1k; R_0603_1608Metric
R50: 23k7; R_0603_1608Metric
kibuzzard-6785F55D: G***; kibuzzard-6785F55D
kibuzzard-67848C10: G***; kibuzzard-67848C10
kibuzzard-67848C36: G***; kibuzzard-67848C36

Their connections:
/DC-DC-Converters/DC-DC-Buck-Converter2/FB: C78.2, C83.1; also elsewhere on the board
/DC-DC-Converters/DC-DC-Buck-Converter2/Output: R34.2; also elsewhere on the board
/DC-DC-Converters/DC-DC-Buck-Converter2/POWER_IN: R24.1, R29.1; also elsewhere on the board
GND: C64.1, C79.1, R23.1, R26.2; also elsewhere on the board
unnamed 55: C75.2; also elsewhere on the board
unnamed: C83.2, R34.1
unnamed 90: R50.1; also elsewhere on the board
unnamed 92: R50.2; also elsewhere on the board
unnamed 95: C75.1, C78.1; also elsewhere on the board
unnamed 96: R23.2, R24.2; also elsewhere on the board
unnamed 98: C79.2, R30.1; also elsewhere on the board
unnamed 100: R26.1; also elsewhere on the board
unnamed 101: C64.2; also elsewhere on the board
unnamed 102: R30.2; also elsewhere on the board
unnamed 104: R29.2; also elsewhere on the board

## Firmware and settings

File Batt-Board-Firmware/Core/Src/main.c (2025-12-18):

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
/* Includes ------------------------------------------------------------------*/
#include "main.h"
#include "cmsis_os.h"
#include "adc.h"
#include "dma.h"
#include "fdcan.h"
#include "i2c.h"
#include "usb_device.h"
#include "gpio.h"

/* USER CODE BEGIN Includes */

#include "ssd1306.h"
#include "ssd1306_tests.h"
#include "ssd1306_fonts.h"
#include "ecocar_can.h"
//#include "usb_device.h"  // Add this line to include the USB device header
//#include "usbd_cdc_if.h" // Add this line to include the USB device header
#include <string.h>
#include <stdbool.h>
/* USER CODE END Includes */


void SystemClock_Config(void);
void MX_FREERTOS_Init(void);
/**
  * @brief  The application entry point.
  * @retval int
  */
int main(void)
{

  /* MCU Configuration--------------------------------------------------------*/

  /* Reset of all peripherals, Initializes the Flash interface and the Systick. */
  HAL_Init();

  /* Configure the system clock */
  SystemClock_Config();

  /* Initialize all configured peripherals */
  MX_GPIO_Init();
  MX_DMA_Init();
  MX_ADC1_Init();
  MX_ADC2_Init();
  MX_FDCAN2_Init();
  MX_I2C1_Init();
  /* Init scheduler */
  osKernelInitialize();

  /* Call init function for freertos objects (in cmsis_os2.c) */
  MX_FREERTOS_Init();

  /* Start scheduler */
  osKernelStart();

  /* We should never get here as control is now taken by the scheduler */

  /* Infinite loop */
  /* USER CODE BEGIN WHILE */
	while (1) {

    /* USER CODE END WHILE */

    /* USER CODE BEGIN 3 */

	}
  /* USER CODE END 3 */
}

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
/**
  * @brief  Period elapsed callback in non blocking mode
  * @note   This function is called  when TIM20 interrupt took place, inside
  * HAL_TIM_IRQHandler(). It makes a direct call to HAL_IncTick() to increment
  * a global variable "uwTick" used as application time base.
  * @param  htim : TIM handle
  * @retval None
  */
void HAL_TIM_PeriodElapsedCallback(TIM_HandleTypeDef *htim)
{
  if (htim->Instance == TIM20) {
    HAL_IncTick();
  }
}

/**
  * @brief  This function is executed in case of error occurrence.
  * @retval None
  */
void Error_Handler(void)
{
  /* USER CODE BEGIN Error_Handler_Debug */
	/* User can add his own implementation to report the HAL error return state */
	__disable_irq();
	while (1) {
	}
  /* USER CODE END Error_Handler_Debug */
}

#ifdef  USE_FULL_ASSERT
/**
  * @brief  Reports the name of the source file and the source line number
  *         where the assert_param error has occurred.
  * @param  file: pointer to the source file name
  * @param  line: assert_param error line source number
  * @retval None
  */
void assert_failed(uint8_t *file, uint32_t line)
{
  /* USER CODE BEGIN 6 */
  /* User can add his own implementation to report the file name and line number,
     ex: printf("Wrong parameters value: file %s on line %d\r\n", file, line) */
  /* USER CODE END 6 */
}
#endif /* USE_FULL_ASSERT */

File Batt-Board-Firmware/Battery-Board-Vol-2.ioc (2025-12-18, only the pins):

Mcu.UserName=STM32G491KEUx
PA0.GPIO_Label=BUCK_TEMP_SENSE
PA0.Signal=ADC1_IN1
PA1.GPIO_Label=OP_TEMP_SENSE
PA1.Signal=ADC1_IN2
PA10.GPIO_Label=GPLED2
PA10.Signal=GPIO_Output
PA11.Signal=USB_DM
PA12.Signal=USB_DP
PA13.Signal=SYS_JTMS-SWDIO
PA14.Signal=SYS_JTCK-SWCLK
PA15.Signal=I2C1_SCL
PA2.GPIO_Label=CNTLR_TEMP_SENSE
PA2.Signal=ADC1_IN3
PA3.GPIO_Label=VMON_IN
PA3.Signal=ADC1_IN4
PA4.GPIO_Label=IMON_IN
PA4.Signal=ADC2_IN17
PA5.GPIO_Label=GPLED3
PA5.Signal=GPIO_Output
PA6.GPIO_Label=IMON_7V
PA6.Signal=ADC2_IN3
PA7.GPIO_Label=VMON_7V
PA7.Signal=ADC2_IN4
PA8.Signal=RCC_MCO
PA9.GPIO_Label=GPLED1
PA9.Signal=GPIO_Output
PB0.GPIO_Label=IMON_12V
PB0.Signal=ADC1_IN15
PB3.GPIO_Label=PG_7V
PB3.Signal=GPIO_Input
PB4.GPIO_Label=PG_12V
PB4.Signal=GPIO_Input
PB5.Signal=FDCAN2_RX
PB6.Signal=FDCAN2_TX
PB7.Signal=I2C1_SDA
PF0-OSC_IN.Signal=RCC_OSC_IN
PF1-OSC_OUT.GPIO_Label=VMON_12V
PF1-OSC_OUT.Signal=ADC2_IN10

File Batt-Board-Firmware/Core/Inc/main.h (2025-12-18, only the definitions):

#define VMON_12V_Pin GPIO_PIN_1
#define VMON_12V_GPIO_Port GPIOF
#define BUCK_TEMP_SENSE_Pin GPIO_PIN_0
#define BUCK_TEMP_SENSE_GPIO_Port GPIOA
#define OP_TEMP_SENSE_Pin GPIO_PIN_1
#define OP_TEMP_SENSE_GPIO_Port GPIOA
#define CNTLR_TEMP_SENSE_Pin GPIO_PIN_2
#define CNTLR_TEMP_SENSE_GPIO_Port GPIOA
#define VMON_IN_Pin GPIO_PIN_3
#define VMON_IN_GPIO_Port GPIOA
#define IMON_IN_Pin GPIO_PIN_4
#define IMON_IN_GPIO_Port GPIOA
#define GPLED3_Pin GPIO_PIN_5
#define GPLED3_GPIO_Port GPIOA
#define IMON_7V_Pin GPIO_PIN_6
#define IMON_7V_GPIO_Port GPIOA
#define VMON_7V_Pin GPIO_PIN_7
#define VMON_7V_GPIO_Port GPIOA
#define IMON_12V_Pin GPIO_PIN_0
#define IMON_12V_GPIO_Port GPIOB
#define GPLED1_Pin GPIO_PIN_9
#define GPLED1_GPIO_Port GPIOA
#define GPLED2_Pin GPIO_PIN_10
#define GPLED2_GPIO_Port GPIOA
#define PG_7V_Pin GPIO_PIN_3
#define PG_7V_GPIO_Port GPIOB
#define PG_12V_Pin GPIO_PIN_4
#define PG_12V_GPIO_Port GPIOB

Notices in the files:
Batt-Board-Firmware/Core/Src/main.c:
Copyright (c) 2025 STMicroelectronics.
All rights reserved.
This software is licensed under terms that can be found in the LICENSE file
